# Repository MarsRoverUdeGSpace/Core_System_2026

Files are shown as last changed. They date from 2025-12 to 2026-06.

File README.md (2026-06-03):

# Core System 2026

Core electronics, embedded firmware, and ROS 2 integration workspace for the UdeG Space 2026 rover platform.

Project logo

## Overview

This repository contains the validated `Kukulcan Rev A` controller hardware, the primary rover MCU firmware, and the ROS 2 workspace used to integrate the embedded system with the rest of the stack.

The current main firmware path, `kukulcan/firmware/upio-ros2/`, is a working ESP32-S3 implementation built on Arduino, FreeRTOS, and micro-ROS, with an AUTOSAR-inspired layered architecture deployed on real hardware.

This MCU sits at the intersection of the rover core system and the autonomous navigation stack for the Mars Rover UdeG Space Maya rover in URC 2026. It concentrates the odometry and control interfaces needed for vehicle state estimation and low-level motion integration, including wheel encoders, dual-IMU integration across the wider system, GNSS, altimeter data, communications with RoboClaw motor controllers, and communications with the main processing unit based on the NVIDIA Jetson Orin Nano.

The platform has already been validated on real hardware and is intended to continue system-level validation during field testing, including work planned for the Mars Desert Research Station.

## Current release state

This repository is past initial bring-up and already contains active work in four areas:

- `kukulcan/hardware/`: KiCad MCU design, 3D exports, fabrication outputs, and PCBA files for `MCU RevA`
- `kukulcan/firmware/upy/`: MicroPython-based sensor and UI bring-up
- `kukulcan/firmware/upio-ros2/`: ESP32-S3 PlatformIO firmware using Arduino, FreeRTOS, micro-ROS, and an AUTOSAR-inspired layered architecture
- `src/`: ROS 2 workspace with custom messages, a local `teleop_twistmux_node`, and vendored micro-ROS packages

As of June 2, 2026, this repository is the stable core-system release line for the rover MCU and ROS-facing embedded interface used by AutoNav.

Current status summary:

- hardware: validated RevA integration board with tracked manufacturing outputs
- firmware: stable release on real hardware with successful `pio run`
- localization interface: firmware-owned epoch-stamped `/odom`, direct BNO055 IMU, magnetometer, and GNSS streams validated on the Kukulcan PCB and consumed by the AutoNav stack
- ROS 2 workspace: active and buildable for the currently used packages
- control interface: `cmd_vel` response and motor timeout behavior corrected for the stable AutoNav integration path

Verified in this repository review:

- `colcon build --packages-select teleop_twistmux_node micro_ros_msgs drive_base_msgs`
- maintainer-provided successful `pio run` result for `upio-ros2`

## Stable release notes

This release promotes `feature/imu-mag-calibration` as the stable source line for `develop` and `main`.

Release highlights:

- integrated wheel odometry publication from RoboClaw encoder ticks
- added BNO055 magnetometer publishing for Jetson-side calibration and localization checks
- stabilized GNSS `NavSatFix`, IMU, magnetometer, and `/odom` timestamps in ROS epoch time
- made `/odom` reliable so full `nav_msgs/msg/Odometry` samples survive XRCE transport size limits
- bounded reliable publisher waits and scheduler catch-up behavior so delayed odometry acknowledgements do not starve IMU/GNSS publication
- calibrated odometry geometry and ticks-per-revolution values for the physical rover
- corrected `cmd_vel` response behavior and retained independent motor safety timeout handling

## Highlights

- `Kukulcan Rev A` is a 4-layer protected controller board built around an `ESP32-S3R8` with added `32 MB` flash
- the firmware architecture treats micro-ROS as the effective RTE boundary and FreeRTOS tasks as the application execution model
- the project has a reliable micro-ROS + FreeRTOS + Arduino implementation on the target MCU
- firmware `/odom` and direct IMU/GNSS topics now provide the validated inputs for Jetson-side EKF/global-localization testing
- the Jetson-side integration path is already designed into the hardware through the 40-pin expansion/control header

## Repository layout

| Path | Purpose |
| --- | --- |
| `kukulcan/hardware/` | MCU KiCad project, local libraries, manufacturing outputs |
| `kukulcan/firmware/` | Embedded firmware projects |
| `src/` | ROS 2 workspace packages and vendored dependencies |
| `docs/` | Datasheets, design notes, images, and release support material |
| `CONTRIBUTING.md` | Lightweight workflow and contribution rules |

## Primary subsystems

- Hardware: [kukulcan/hardware/README.md](kukulcan/hardware/README.md)
- Firmware: [kukulcan/firmware/README.md](kukulcan/firmware/README.md)
- Main firmware track: [kukulcan/firmware/upio-ros2/README.md](kukulcan/firmware/upio-ros2/README.md)

## Firmware architecture direction

The main embedded firmware track, `upio-ros2`, is not just an implementation of drivers and ROS transport. It is also the project's embedded software architecture reference:

- application logic is kept separate from hardware-facing details
- the runtime environment layer is effectively realized through the micro-ROS integration boundary
- hardware-dependent behavior is pushed into HAL-style modules and lower layers
- FreeRTOS tasking is used to preserve deterministic behavior across sensing, publishing, and actuation paths, effectively expressing the application layer execution model

That AUTOSAR-inspired separation is already a validated project strength and should be treated as part of the stable release narrative. The same applies to the reliable micro-ROS + FreeRTOS + Arduino implementation on the target MCU, which meaningfully reduces integration friction for the rover stack.

## Quick start

```bash
git clone git@github.com:MarsRoverUdeGSpace/Core_System_2026.git
cd Core_System_2026
git checkout main
```

ROS 2 packages can be listed with:

```bash
colcon list
```

The `upio-ros2` firmware lives in:

```bash
cd kukulcan/firmware/upio-ros2
pio run
```

The hardware project opens from:

```text
kukulcan/hardware/MCU/MCU.kicad_pro
```

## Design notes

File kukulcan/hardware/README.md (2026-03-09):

# Kukulcan Hardware

This directory contains the MCU hardware design and tracked fabrication artifacts for the Kukulcan rover controller board.

Current documented board target: `Kukulcan Rev A`, described as validated RevA integration hardware.

## Contents

- `MCU/`: main KiCad project, board file, schematic, local outputs, and board exports
- `Libraries/`: shared symbols, footprints, and 3D models used by the design
- `mfr/`: tracked manufacturing outputs, Gerbers, drills, fab zip, BOM, and CPL

## Primary design files

- Project: `MCU/MCU.kicad_pro`
- Schematic: `MCU/MCU.kicad_sch`
- PCB: `MCU/MCU.kicad_pcb`
- Board solid: `MCU/MCU.stl`
- Exported board model: `MCU/outputs/MCU_board.step`
- Exported schematic PDF: `MCU/outputs/MCU_schematic.pdf`

## Board overview

Kukulcan Rev A is a 4-layer ESP32-based rover controller board intended to bridge embedded control, onboard sensing, and Jetson-side ROS integration.

Key design points:

- MCU: `ESP32-S3R8` with additional `32 MB` flash
- PCB size: `78 x 53 mm`
- PCB thickness: `1.6 mm`
- Copper weight: `1 oz`
- Surface finish: `HASL with lead`
- Mounting: `M3` mounting holes
- Debug/programming: USB JTAG support for programming and debugging

## Power architecture

The board uses a protected `5 V` input architecture with separate power intent for core electronics and auxiliary lighting.

- Allowed input: `5 V`
- Main power entry: two barrel-jack inputs
- Main regulated logic rail: `3.3 V` generated from `5 V` through a `TLV1117-33` LDO
- Auxiliary power rail: separate `5 V` rail for the LED strip
- Power implementation emphasis: three power planes across the 4-layer board

Documented protection features:

- fuse protection
- reverse-polarity protection
- ESD protection
- TVS protection

## Integrated and exposed interfaces

Integrated devices:

- GNSS: `u-blox NEO-M8N`, mounted directly on the PCB
- Barometer/environmental sensor: `BME280`
- IMU: `BNO055`

External connectivity:

- Jetson interface: `40-pin` header intended for ribbon-cable connection to the Jetson Orin Nano as a broader expansion/control interface
- Jetson link currently includes UART plus two GPIO lines connected to the ESP32
- Jetson-side dedicated I2C is reserved for the `BMI088` IMU
- RoboClaw communications: exposed UART
- Expansion bus: exposed I2C header for additional peripherals
- GNSS antenna: coaxial connector for an active GNSS antenna

Planned but not yet implemented:

- external `2.4"` diagnostics display on the exposed I2C bus

## Validation status

Kukulcan Rev A is validated RevA integration hardware.

Maintainer-reported validation status:

- stable embedded firmware can run on the board
- most hardware functions have been validated on real hardware
- GNSS validation is still pending
- diagnostics display support is still pending

## Manufacturing status

Tracked fabrication data already exists for `MCU RevA`:

- Gerbers and drills in `mfr/`
- Fabrication archive in `mfr/MCU_revA_fab.zip`
- Assembly files in `mfr/pcba/`

If the PCB changes, regenerate these outputs in the same commit or a clearly paired follow-up commit.

## Validation evidence

### PCB render

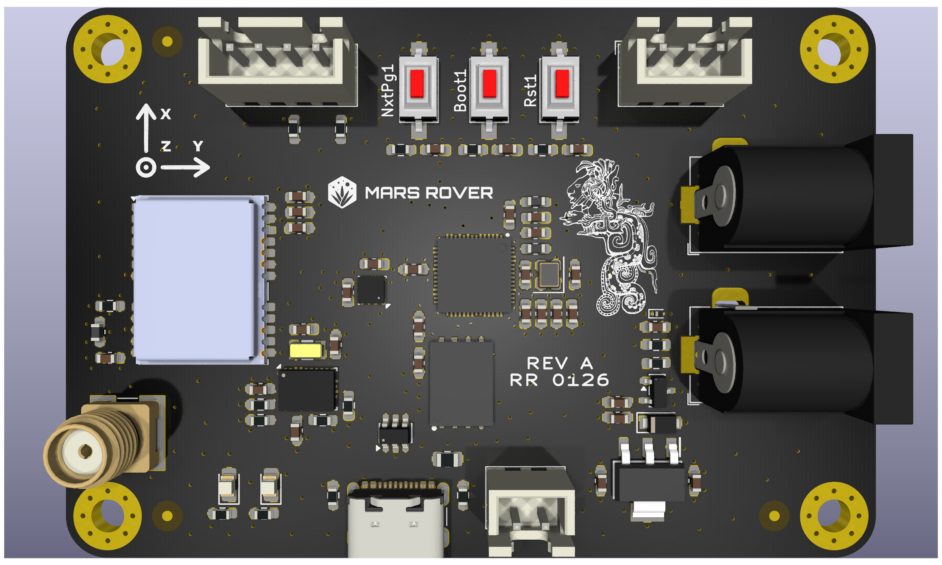
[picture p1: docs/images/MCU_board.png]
Kukulcan Rev A PCB render


Current board render for Kukulcan Rev A.

### Real hardware

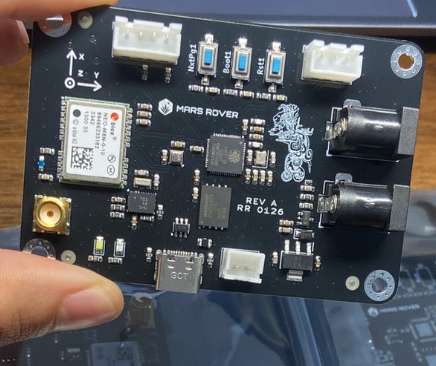
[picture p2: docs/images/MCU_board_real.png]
Kukulcan Rev A assembled board


Assembled Kukulcan Rev A board photographed on real hardware.

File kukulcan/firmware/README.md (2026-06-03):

# Kukulcan Firmware

This directory groups the embedded firmware projects for the Kukulcan controller stack.

The controller firmware in this repository is part of the rover core system and the autonomous navigation stack for the Mars Rover UdeG Space Maya rover in URC 2026. It is responsible for the MCU-side integration of sensing, low-level actuation interfaces, and communication with the Jetson Orin Nano main processing unit.

## Status

The firmware work in this repository is split into two tracks with different roles:

- `upy/`: used for rapid prototyping, sensor bring-up, and integration testing validation
- `upio-ros2/`: current real implementation on ESP32-S3 using PlatformIO, Arduino, FreeRTOS, and micro-ROS

## Projects

- `upy/`: MicroPython-based rapid prototyping and validation path
- `upio-ros2/`: stable firmware implementation and primary release-facing embedded stack

## Current validation

Physical Kukulcan validation confirmed the `upio-ros2/` ROS-facing localization contract: firmware publishes epoch-stamped `/odom`, `/sensors/bno055/imu/data`, `/sensors/bno055/mag`, and `/sensors/gnss/fix` without the prior multi-second publish stalls. The AutoNav Jetson integration path consumes this odometry, IMU, magnetometer, and GNSS contract directly; detailed rates, transport constraints, scheduling behavior, and smoke-test commands are documented in [`upio-ros2/README.md`](upio-ros2/README.md).

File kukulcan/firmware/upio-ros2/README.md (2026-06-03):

# upio-ros2

ESP32-S3 firmware for the Kukulcan MCU using PlatformIO, Arduino, FreeRTOS, and micro-ROS.

## Scope

This firmware is the current embedded integration path between the MCU hardware and the ROS 2 stack. It already includes:

- micro-ROS transport setup
- `cmd_vel` consumption
- motor control tasking
- encoder publishing
- IMU publishing
- GNSS publishing
- wheel odometry publishing
- barometer publishing
- status LED handling

The architecture itself is a primary feature of this firmware: a micro-ROS and FreeRTOS compatible AUTOSAR-style separation between application logic, runtime integration, hardware abstraction, and deterministic task scheduling.

## AUTOSAR-style architecture

This project intentionally emphasizes architecture, not only peripheral bring-up. The firmware follows an AUTOSAR-inspired layered model adapted to the ESP32-S3 and rover use case:

- application layer: mission-facing logic and task orchestration
- runtime environment: controlled interface between application behavior and ROS communication paths
- service and abstraction layers: reusable system services and ECU-facing abstractions
- microcontroller and hardware-facing layers: board-specific buses, peripherals, and device drivers

In repository terms, that maps roughly to:

| Layer intent | Current implementation |
| --- | --- |
| Application Layer | `lib/app/` and its FreeRTOS task model |
| AUTOSAR Runtime Environment | `lib/rte/`, implemented around micro-ROS |
| ECU abstraction and complex drivers | `lib/hal_*`, parts of `lib/config/` |
| MCU-specific configuration | `lib/config/`, board definition, Arduino/ESP32 interfaces |

This architectural separation is already part of the validated firmware value and should be described as a deliberate stable-release feature, not just an internal code organization choice.

In practical terms for this project:

- the RTE layer is essentially the micro-ROS integration boundary
- the application layer is effectively expressed through coordinated FreeRTOS tasks
- the lower layers hold the hardware-specific behavior needed to keep the application side portable and organized

## micro-ROS implementation significance

This firmware also demonstrates a reliable implementation of micro-ROS on top of FreeRTOS with the Arduino framework on ESP32-S3 hardware. That matters because current documentation around this combination is still weaker than the more common reference paths.

For this project, that combination is not experimental anymore. It is part of the validated embedded stack and materially lowers the integration barrier for rover development by:

- simplifying embedded ROS 2 adoption on the target MCU
- preserving a practical Arduino-based development flow
- keeping deterministic task partitioning through FreeRTOS
- exposing ROS communication through an architecture-aligned RTE layer

## Architecture diagrams

### AUTOSAR-inspired layering

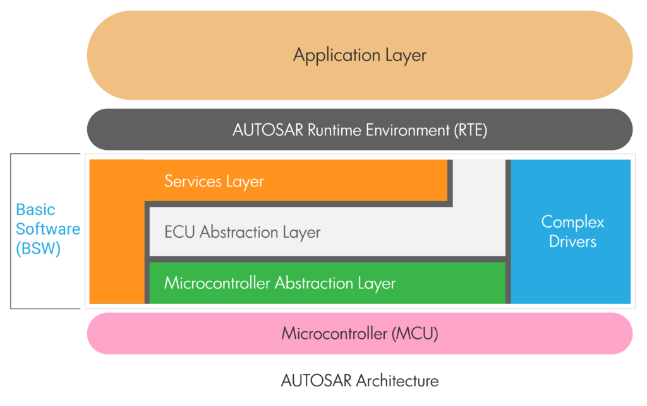
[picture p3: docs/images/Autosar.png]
AUTOSAR-inspired firmware architecture


AUTOSAR-inspired layering used by the firmware. In this project, the runtime environment is effectively realized through micro-ROS and the application layer is expressed through coordinated FreeRTOS tasks.

### micro-ROS stack reference

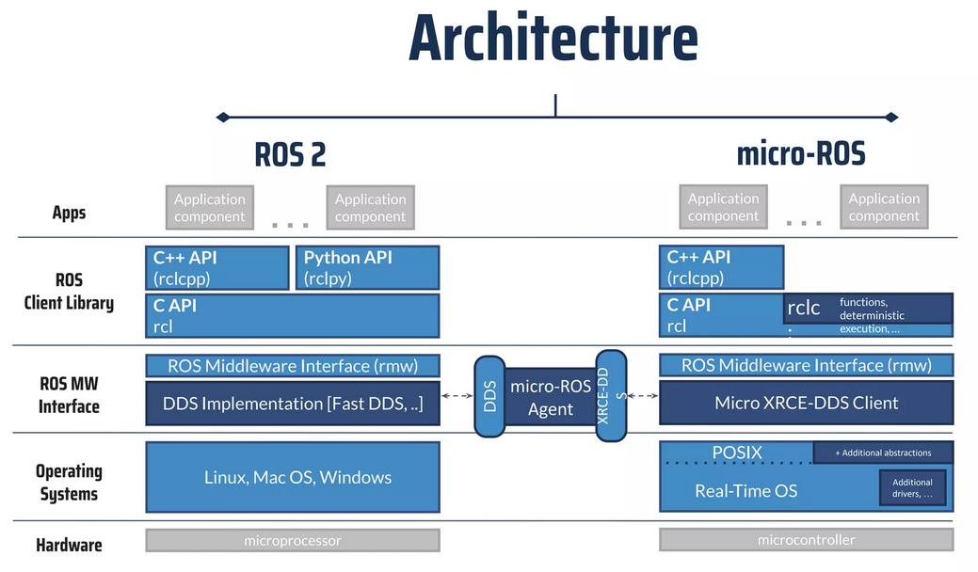
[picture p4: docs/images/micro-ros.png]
micro-ROS architecture reference


micro-ROS architecture reference for the implemented FreeRTOS plus Arduino stack on the ESP32-S3 target.

## Layout

| Path | Purpose |
| --- | --- |
| `src/main.cpp` | Arduino entry point |
| `lib/app/` | task creation and scheduling |
| `lib/rte/` | micro-ROS runtime integration |
| `lib/config/` | hardware pins, buses, queues, and shared objects |
| `lib/hal_*` | hardware abstraction modules for motors, encoders, IMU, altitude, and status LEDs |
| `platformio.ini` | PlatformIO environment and dependencies |

## Runtime model

The current architecture follows the intent described in `AGENTS.md`:

- one task services micro-ROS executor work
- one publisher task emits cached sensor data at fixed periods
- one motor task consumes `cmd_vel` messages and applies a timeout stop
- sensor work lives in dedicated HAL tasks instead of inside the executor

This is the stable release runtime model because it keeps sensor access, motor control, and ROS communication separated while preserving bounded latency for the AutoNav stack.

## Sensor and odometry runtime behavior

The firmware intentionally prioritizes motor control and the micro-ROS runtime loop while keeping sensor traffic at rates appropriate for localization and diagnostics:

| Topic or operation | Configured rate | Notes |
| --- | ---: | --- |
| micro-ROS executor work | 200 Hz | `5 ms` application/RTE period |
| motor control update | 100 Hz | `10 ms` motor task; unchanged commands are not retransmitted to RoboClaw |
| `/sensors/bno055/imu/data` | 25 Hz | Quaternion, angular velocity, and linear acceleration with covariance |
| `/sensors/bno055/mag` | 5 Hz | Magnetic field diagnostic/localization input |
| `/sensors/gnss/fix` | 5 Hz | `NavSatFix`; fix status indicates whether coordinates are valid |
| `/sensors/roboclaw/encoders/*/ticks` | 10 Hz | Primary raw encoder telemetry used to validate wheel acquisition |
| `/sensors/roboclaw/encoders/*/qpps` | Diagnostic only | Sampled periodically; never gates tick validity or odometry |
| `/odom` | 10 Hz | Wheel odometry with `odom` -> `base_footprint` frames |
| `/sensors/bme280/*` | 1 Hz | Environmental telemetry |

Sensor HAL tasks share the I2C bus through a mutex. The BNO055 task retries initialization after boot-time failures rather than requiring a controller reset. RoboClaw wheel tick reads are the validity source for odometry; optional QPPS reads are deliberately excluded from that path so a failed diagnostic query cannot discard usable encoder data.

`/odom` must use reliable micro-ROS QoS. Its serialized `nav_msgs/msg/Odometry` payload includes two covariance matrices and exceeds the `512` byte best-effort XRCE transport MTU configured by the generated micro-ROS client library. Reliable transport provides fragmentation history for the full message; changing `/odom` back to best-effort results in a discovered publisher with no received odometry samples. Reliable publisher session waits are bounded to `5 ms` so an odometry acknowledgement delay cannot stall the shared publisher task and starve IMU or GNSS output.

Timestamped localization topics use synchronized ROS epoch time only. The RTE captures a synchronized epoch/monotonic anchor and derives publish stamps locally without taking the micro-ROS transport mutex on every sensor sample. Before epoch synchronization is available, timestamped localization samples are withheld rather than being emitted in MCU uptime time. This prevents mixed time domains from entering EKF or NavSat processing.

The publisher scheduler skips missed slots after a transport delay rather than replaying a burst of overdue messages. Health pings are serialized with the RCL transport and run at `1 Hz`; the independent motor command timeout remains `250 ms`.

## Stable release integration notes

The June 2026 stable release is the firmware contract used by the AutoNav GNSS waypoint navigation milestone. The important integration guarantees are:

- `/odom` is firmware-owned wheel odometry derived from RoboClaw encoder ticks, calibrated ticks-per-revolution, and calibrated rover geometry.
- `/sensors/bno055/imu/data`, `/sensors/bno055/mag`, `/sensors/gnss/fix`, and `/odom` use ROS epoch timestamps only.
- magnetometer output is available for Jetson-side IMU/magnetic calibration checks.
- reliable `/odom` publication is required because the payload is larger than the best-effort XRCE MTU.
- reliable publisher waits are bounded and missed scheduler periods are skipped, preventing odometry acknowledgement delays from blocking GNSS or IMU output.
- motor command handling responds to `cmd_vel` changes while retaining the independent `250 ms` stop timeout.

## Firmware flow

```mermaid
flowchart LR
  A[FreeRTOS Application Tasks<br/>lib/app] --> B[micro-ROS RTE<br/>lib/rte]
  A --> C[HAL Modules<br/>lib/hal_*]
  B --> D[ROS 2 Agent]
  C --> E[Motors]
  C --> F[IMU]
  C --> G[BME280]
  C --> H[Encoders]
  I[lib/config] --> A
  I --> B
  I --> C
```

This diagram reflects the project's practical layering: FreeRTOS tasks drive application behavior, `lib/rte` exposes the micro-ROS communication boundary, and HAL modules own the hardware-facing work.

## Build

```bash
cd kukulcan/firmware/upio-ros2
pio run
```

Flash:

```bash
pio run -t upload
```

## Current validation status

Maintainer-reported status for the stable release:

- Firmware status: stable release
- Tested hardware: Kukulcan PCB
- Build status: successful `pio run`
- Validation level: thoroughly tested by the maintainer for the current stable AutoNav integration scope

Validated on physical hardware on 2026-05-26:

- BNO055 IMU output observed near the configured `25 Hz` rate.
- BNO055 magnetometer and GNSS output observed at `5 Hz`.
- RoboClaw left and right tick topics observed near the configured `10 Hz` rate after eliminating unnecessary UART traffic and optional-QPPS gating.
- Reliable `/odom` output observed at `10 Hz` while stationary, with `frame_id: odom`, `child_frame_id: base_footprint`, valid timestamp, and zero stationary twist.

Validated again on physical hardware on 2026-05-27 after the ROS epoch and reliable-publisher scheduling fix:

- `/sensors/bno055/imu/data`, `/sensors/gnss/fix`, and `/odom` reported ROS epoch timestamps in the same time domain; the prior IMU uptime stamp failure was removed.
- `/odom` held near `10.2 Hz`, `/sensors/gnss/fix` near `4.8-5.0 Hz`, and `/sensors/bno055/mag` near `5.0 Hz` without the earlier multi-second publication stalls.
- `/sensors/bno055/imu/data` recovered to approximately `22-23.6 Hz` during the captured sample. This is adequate for the current PCB/EKF integration gate, but remains below the configured `25 Hz` target and should be monitored during motion testing.
- Short zero/minimum intervals were still visible in `ros2 topic hz` output. No multi-second starvation remained, but transport jitter should be rechecked if EKF timing warnings reappear.

Latest confirmed build result provided by the maintainer:

```text
==================== [SUCCESS] Took 10.34 seconds ====================
RAM:   16.0% (used 52568 bytes from 327680 bytes)
Flash: 8.9% (used 420573 bytes from 4718592 bytes)
```

## Transport and agent

Current validated serial agent command:

```bash
ros2 run micro_ros_agent micro_ros_agent serial --dev /dev/ttyACM0 -b 921600
```

The same workflow can also be run from Docker, which is the expected Jetson-side deployment path.

## Hardware smoke test

After flashing, verify sensor and wheel odometry health before enabling higher-level localization or navigation:

```bash
pio run -t upload
ros2 topic hz /sensors/bno055/imu/data
ros2 topic hz /sensors/bno055/mag
ros2 topic hz /sensors/gnss/fix
ros2 topic hz /sensors/roboclaw/encoders/left_m1/ticks
ros2 topic hz /sensors/roboclaw/encoders/right_m2/ticks
ros2 topic info -v /odom
ros2 topic echo --once /odom
ros2 topic hz /odom
```

Expected stationary result: the IMU is close to `25 Hz`; magnetometer and GNSS are close to `5 Hz`; encoder tick topics are close to `10 Hz`; `/odom` reports reliable QoS and publishes close to `10 Hz` with zero twist. A GNSS message with `status: -1` and zero coordinates confirms communication but means no usable satellite fix has been acquired yet.

All localization stamps must be in ROS epoch time. Any IMU stamp near controller uptime rather than the current ROS epoch is a firmware fault and blocks EKF/NavSat testing.

## Validated behavior

- micro-ROS transport and executor integration
- FreeRTOS task partitioning aligned with the firmware architecture
- AUTOSAR-inspired layered firmware structure validated in real implementation
- `cmd_vel` handling for motor commands
- sensor publishing pipeline
- recoverable BNO055 initialization and serialized shared-I2C access
- RoboClaw encoder acquisition sufficient for wheel odometry
- reliable wheel odometry publication sized for XRCE transport constraints
- epoch-only localization stamping with bounded reliable publication latency

## Operational notes

- Motor control still uses the current low-level command path with safety timeout handling.
- GNSS output requires an outdoor/adequate-signal fix before coordinates are usable for waypoint navigation.
- If EKF timing warnings reappear, first recheck ROS epoch stamping, reliable `/odom` QoS, and publisher scheduler latency before retuning localization.

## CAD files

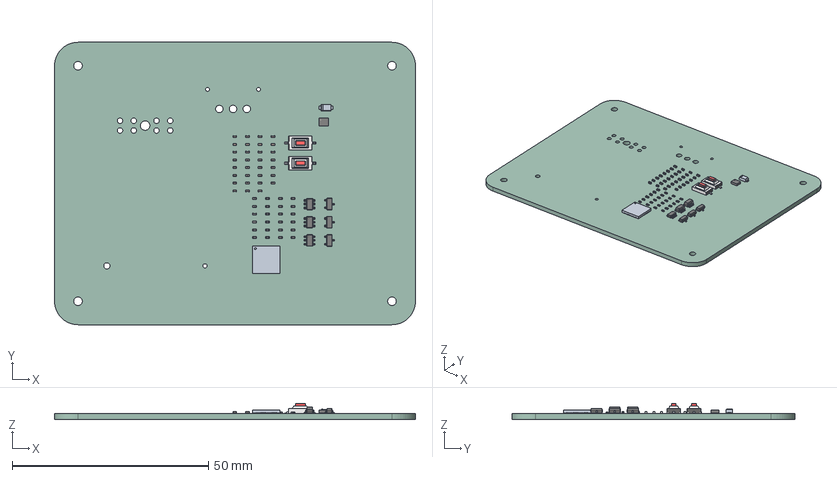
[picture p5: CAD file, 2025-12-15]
kukulcan/hardware/MCU/outputs/MCU_board.step
92.0 x 72.0 x 4.09 mm
L_0402_1005Metric x 4
C_0402_1005Metric x 31
R_0402_1005Metric x 20
SOT-23-6 x 2
MCU_board 1.26.1
SOT-23 x 3
Bosch_LGA-8_2x2.5mm_P0.65mm_ClockwisePinNumbering
TSOT-23-6
SW_SPST_CK_RS282G05A3 x 2
MCU_board 1.35.1
MCU_PCB

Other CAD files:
kukulcan/hardware/MCU/MCU.stl

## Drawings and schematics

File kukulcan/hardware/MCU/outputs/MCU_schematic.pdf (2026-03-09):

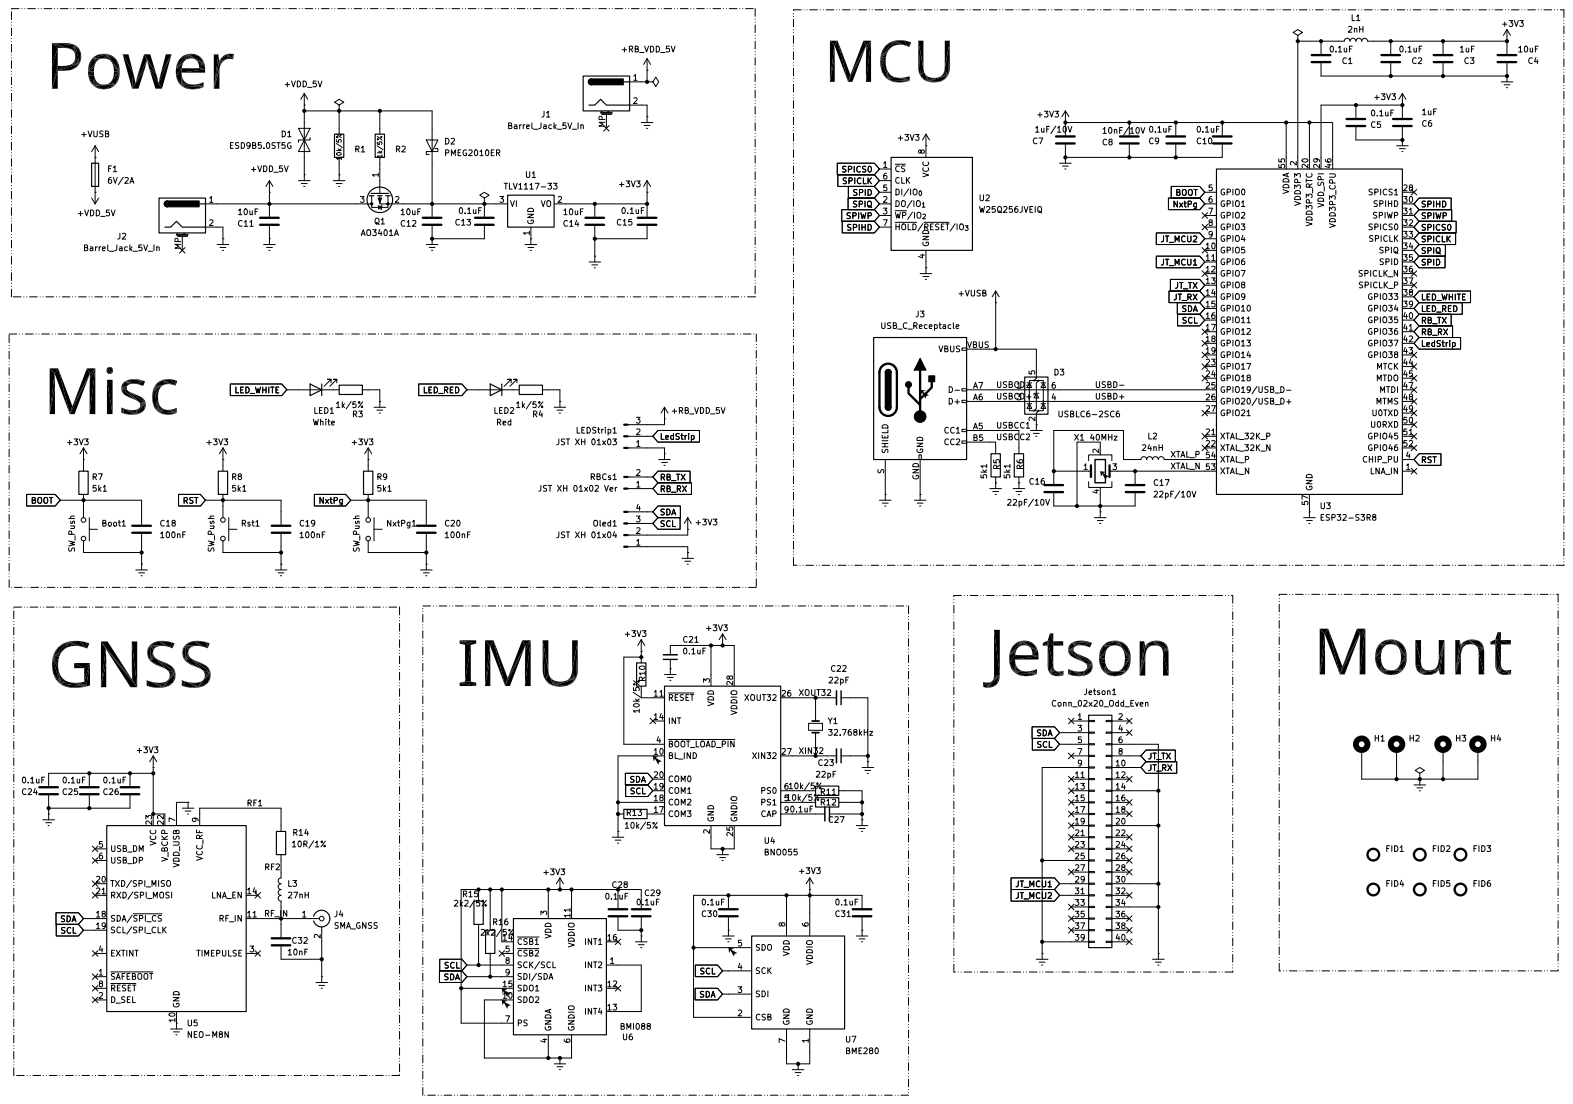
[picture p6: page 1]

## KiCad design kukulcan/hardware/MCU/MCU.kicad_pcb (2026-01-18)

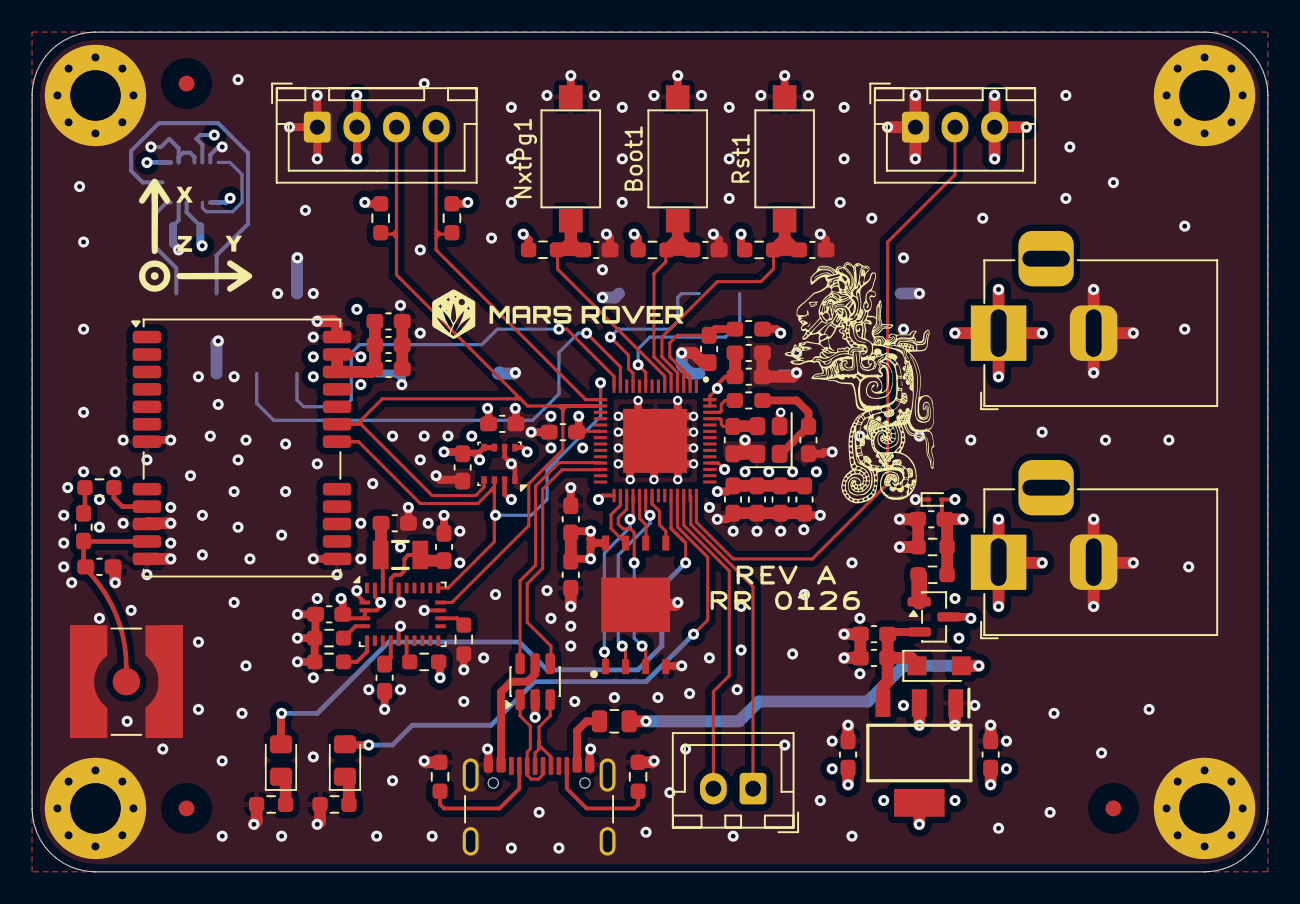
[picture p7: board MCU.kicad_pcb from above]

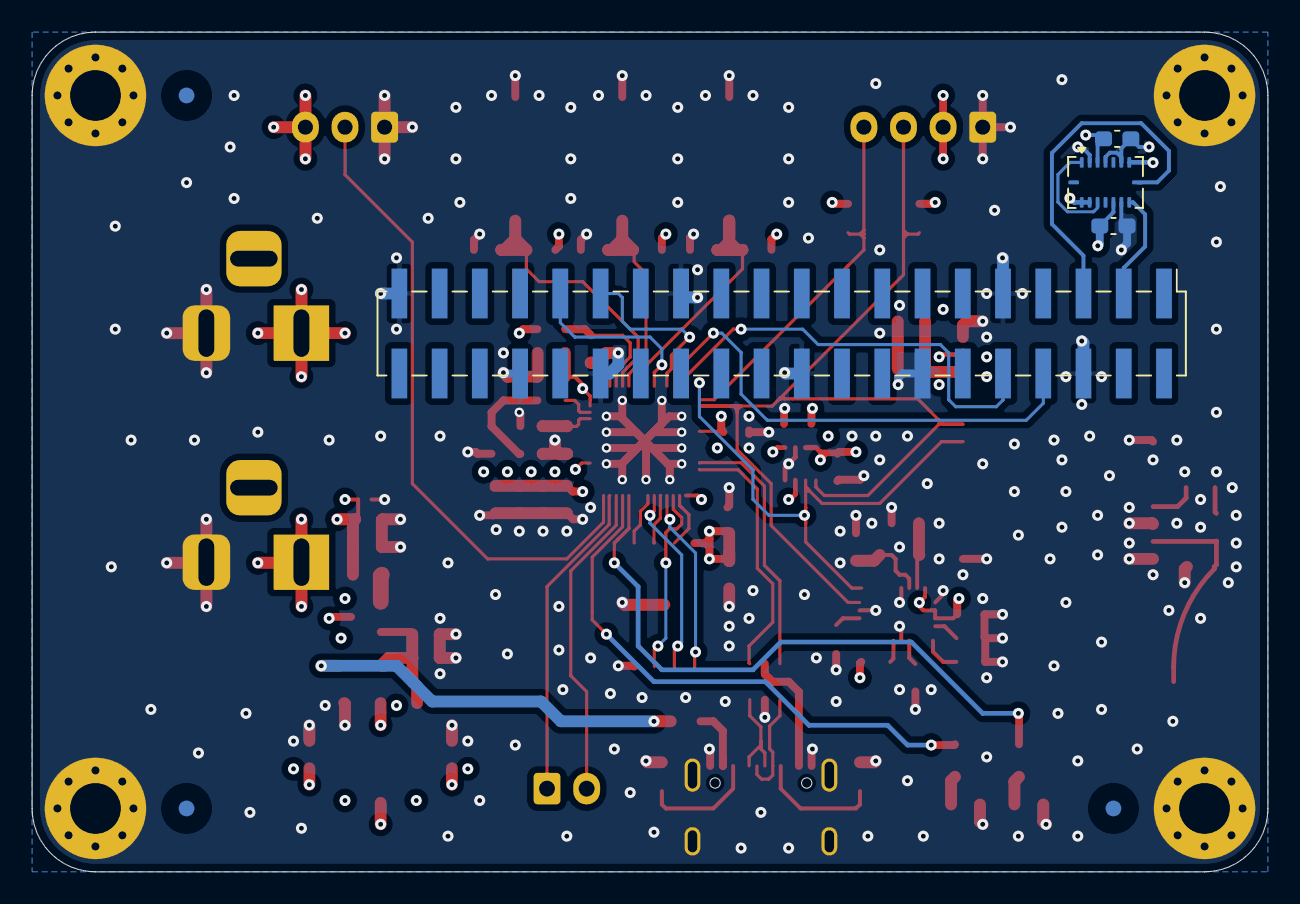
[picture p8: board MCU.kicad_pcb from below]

Board: 4 copper layers, 78.0 x 53.0 mm, 91 parts (7 on the bottom side), 50 nets.

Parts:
Boot1: SW_Push; SW_SPST_CK_RS282G05A3
C1, C2, C5, C9, C10, C13, C15, C21, C24, C25, C26, C27, C28, C29, C30, C31: 0.1uF; C_0603_1608Metric_Pad1.08x0.95mm_HandSolder
C3, C6: 1uF; C_0603_1608Metric_Pad1.08x0.95mm_HandSolder
C4, C11, C12, C14: 10uF; C_0603_1608Metric_Pad1.08x0.95mm_HandSolder
C7: 1uF/10V; C_0603_1608Metric_Pad1.08x0.95mm_HandSolder
C8: 10nF/10V; C_0603_1608Metric_Pad1.08x0.95mm_HandSolder
C16, C17: 22pF/10V; C_0603_1608Metric_Pad1.08x0.95mm_HandSolder
C18, C19, C20: 100nF; C_0603_1608Metric_Pad1.08x0.95mm_HandSolder
C22, C23: 22pF; C_0603_1608Metric_Pad1.08x0.95mm_HandSolder
C32: 10nF; C_0603_1608Metric_Pad1.08x0.95mm_HandSolder
D1: ESD9B5.0ST5G; D_SOD-923
D2: PMEG2010ER; Nexperia_CFP3_SOD-123W
D3: USBLC6-2SC6; SOT-23-6
F1: 6V/2A; Fuse_0805_2012Metric
FID1, FID2, FID3, FID4, FID5, FID6: Fiducial; Fiducial_1mm_Mask3mm
H1, H2, H3, H4: MountingHole_Pad; MountingHole_3.2mm_M3_Pad_Via
J1, J2: Barrel_Jack_5V_In; BarrelJack_Horizontal
J3: USB_C_Receptacle; USB_C_Receptacle_GCT_USB4105-xx-A_16P_TopMnt_Horizontal
J4: SMA_GNSS; SMA_Amphenol_132134-10_Vertical
Jetson1: Conn_02x20_Odd_Even; PinHeader_2x20_P2.54mm_Vertical_SMD
L1: 2nH; L_0603_1608Metric_Pad1.05x0.95mm_HandSolder
L2: 24nH; L_0603_1608Metric_Pad1.05x0.95mm_HandSolder
L3: 27nH; L_0603_1608Metric_Pad1.05x0.95mm_HandSolder
LED1: White; LED_0805_2012Metric_Pad1.15x1.40mm_HandSolder
LED2: Red; LED_0805_2012Metric_Pad1.15x1.40mm_HandSolder
LEDStrip1: JST XH 01x03; JST_XH_B3B-XH-A_1x03_P2.50mm_Vertical
NxtPg1: SW_Push; SW_SPST_CK_RS282G05A3
Oled1: JST XH 01x04; JST_XH_B4B-XH-A_1x04_P2.50mm_Vertical
Q1: AO3401A; SOT-23
R1, R10, R11, R12, R13, R15, R16: 10k/5%; R_0603_1608Metric_Pad0.98x0.95mm_HandSolder
R2, R3, R4: 1k/5%; R_0603_1608Metric_Pad0.98x0.95mm_HandSolder
R5, R6, R7, R8, R9: 5k1; R_0603_1608Metric_Pad0.98x0.95mm_HandSolder
R14: 10R/1%; R_0603_1608Metric_Pad0.98x0.95mm_HandSolder
RBCs1: JST XH 01x02 Ver; JST_XH_B2B-XH-A_1x02_P2.50mm_Vertical
Rst1: SW_Push; SW_SPST_CK_RS282G05A3
U1: TLV1117-33; SOT230P700X180-4N
U2: W25Q256JVEIQ
U3: ESP32-S3R8
U4: BNO055; LGA-28_5.2x3.8mm_P0.5mm
U5: NEO-M8N; ublox_NEO
U6: BMI088; Bosch_LGA-16_4.5x3mm_P0.5mm_LayoutBorder7x1y_ClockwisePinNu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
U7: BME280; Bosch_LGA-8_2.5x2.5mm_P0.65mm_ClockwisePinNumbering
X1: 40MHz; Crystal_SMD_2520-4Pin_2.5x2.0mm
Y1: 32.768kHz; Crystal_SMD_3.2x1.5mm
svg2mod: G***; kukulcan
svg2mod#2: G***; MarsRover
svg2mod#3: G***; IMU_Axes_XYZ

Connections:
+3V3: C2.1, C3.1, C4.1, C5.1, C6.1, C7.1, C8.1, C9.1, C10.1, C14.1, C15.1, C21.2, C24.1, C25.1, C26.1, C28.1, C29.1, C30.1, C31.1, L1.1, Oled1.2, R7.1, R8.1, R9.1, R10.1, R15.2, R16.2, U1.2 (VO), U1.4, U2.8 (VCC), U3.20 (VDD3P3_RTC), U3.29 (VDD_SPI), U3.46 (VDD3P3_CPU), U3.55 (VDDA), U3.56 (VDDA), U4.3 (VDD), U4.4 (~BOOT_LOAD_PIN), U4.28 (VDDIO), U5.22 (V_BCKP), U5.23 (VCC), U6.3 (VDD), U6.7 (PS), U6.11 (VDDIO), U6.14 (~CSB1), U6.15 (SDO1), U7.2 (CSB), U7.5 (SDO), U7.6 (VDDIO), U7.8 (VDD)
+RB_VDD_5V: J1.1, LEDStrip1.3
+VDD_5V: C11.1, D1.2 (A2), D2.2 (A), F1.2, J2.1, Q1.3 (D), R1.1, R2.1
+VUSB: D3.5 (VBUS), F1.1, J3.A4, J3.A9, J3.B4, J3.B9
/RF1: R14.1, U5.9 (VCC_RF)
/RF2: L3.1, R14.2
/RF_IN: C32.2, J4.1 (In), L3.2, U5.11 (RF_IN)
/USBCC1: J3.A5 (CC1), R6.1
/USBCC2: J3.B5 (CC2), R5.1
/USBCD+: D3.3 (I/O2), J3.A6 (D+), J3.B6 (D+)
/USBCD-: D3.1 (I/O1), J3.A7 (D-), J3.B7 (D-)
/USBD+: D3.4 (I/O2), U3.26 (GPIO20/USB_D+)
/USBD-: D3.6 (I/O1), U3.25 (GPIO19/USB_D-)
/XIN32: C23.2, U4.27 (XIN32), Y1.1
/XOUT32: C22.2, U4.26 (XOUT32), Y1.2
/XTAL_N: C17.1, U3.53 (XTAL_N), X1.3
/XTAL_P: L2.2, U3.54 (XTAL_P)
BOOT: Boot1.1, C18.1, R7.2, U3.5 (GPIO0)
GND: Boot1.2, C1.2, C2.2, C3.2, C4.2, C5.2, C6.2, C7.2, C8.2, C9.2, C10.2, C11.2, C12.2, C13.2, C14.2, C15.2, C16.1, C17.2, C18.2, C19.2, C20.2, C21.1, C22.1, C23.1, C24.2, C25.2, C26.2, C27.1, C28.2, C29.2, C30.2, C31.2, C32.1, D1.1 (A1), D3.2 (GND), H1.1, H2.1, H3.1, H4.1, J1.2, J2.2, J3.A1, J3.A12, J3.B1, J3.B12, J3.S1, J4.2 (Ext), Jetson1.6, Jetson1.9, Jetson1.14, Jetson1.20, Jetson1.25, Jetson1.30, Jetson1.34, Jetson1.39, LEDStrip1.1, NxtPg1.2, Oled1.1, R1.2, R3.1, R4.1, R5.2, R6.2, R11.1, R12.1, R13.1, Rst1.2, U1.1 (GND), U2.4 (GND), U2.9, U3.57 (GND), U4.2 (GND), U4.10 (BL_IND), U4.18 (COM2), U4.25 (GNDIO), U5.7 (VDD_USB), U5.10 (GND), U5.12 (GND), U5.13 (GND), U5.24 (GND), U6.2 (GNDA), U6.4 (GNDA), U6.6 (GNDIO), U6.10 (SDO2), U7.1 (GND), U7.7 (GND), X1.2, X1.4
JT_MCU1: Jetson1.29, U3.11 (GPIO6)
JT_MCU2: Jetson1.31, U3.9 (GPIO4)
JT_RX: Jetson1.10, U3.14 (GPIO9)
JT_TX: Jetson1.8, U3.13 (GPIO8)
LED_RED: LED2.2 (A), U3.39 (GPIO34)
LED_WHITE: LED1.2 (A), U3.38 (GPIO33)
LedStrip: LEDStrip1.2, U3.42 (GPIO37)
unnamed: C1.1, L1.2, U3.2 (VDD3P3), U3.3 (VDD3P3)
unnamed: C16.2, L2.1, X1.1
unnamed: C12.1, C13.1, D2.1 (K), Q1.2 (S), U1.3 (VI)
unnamed: LED1.1 (K), R3.2
unnamed: LED2.1 (K), R4.2
unnamed: Q1.1 (G), R2.2
unnamed: C27.2, U4.9 (CAP)
unnamed: R13.2, U4.17 (COM3)
unnamed: R11.2, U4.6 (PS0)
unnamed: R12.2, U4.5 (PS1)
unnamed: R10.2, U4.11 (~RESET)
unnamed: U6.1 (INT2), U6.13 (INT4)
NxtPg: C20.1, NxtPg1.1, R9.2, U3.6 (GPIO1)
RB_RX: RBCs1.1, U3.41 (GPIO36)
RB_TX: RBCs1.2, U3.40 (GPIO35)
RST: C19.1, R8.2, Rst1.1, U3.4 (CHIP_PU)
SCL: Jetson1.5, Oled1.3, R15.1, U3.16 (GPIO11), U4.19 (COM1), U5.19 (SCL/SPI_CLK), U6.8 (SCK/SCL), U7.4 (SCK)
SDA: Jetson1.3, Oled1.4, R16.1, U3.15 (GPIO10), U4.20 (COM0), U5.18 (SDA/~SPI_CS), U6.9 (SDI/SDA), U7.3 (SDI)
SPICLK: U2.6 (CLK), U3.33 (SPICLK)
SPICS0: U2.1 (~CS), U3.32 (SPICS0)
SPID: U2.5 (DI/IO_{0}), U3.35 (SPID)
SPIHD: U2.7 (~HOLD/~RESET/IO_{3}), U3.30 (SPIHD)
SPIQ: U2.2 (DO/IO_{1}), U3.34 (SPIQ)
SPIWP: U2.3 (~WP/IO_{2}), U3.31 (SPIWP)

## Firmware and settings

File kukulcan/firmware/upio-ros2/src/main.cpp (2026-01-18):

/**
 * @file main.cpp
 * @brief Arduino entry point for upio-ros2 firmware.
 */

#include "app.h"

/**
 * @brief Initialize application layer and start tasks.
 */
void setup(void)
{
  app_Init();
  app_StartTasks();
}

/**
 * @brief Idle loop; work is handled by FreeRTOS tasks.
 */
void loop(void){}

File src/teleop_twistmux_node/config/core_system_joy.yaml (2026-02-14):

core_system:
  ros__parameters:
    joy_topic: "/joy"
    cmd_vel_topic: "/cmd_vel"

    publish_rate_hz: 20.0
    joy_timeout_s: 0.25

    # Axes: adjust if your /joy differs
    axis_linear_x: 1
    axis_angular_z: 0

    # Deadman (must be held to move)
    deadman_button: 5   # RB (common)

    # Speed lock buttons (first pressed wins)
    # Example: A,B,X,Y,LB,RB indices 0..5 (common on Xbox layouts)
    speed_buttons: [0, 1, 2, 3, 4, 5]

    # Presets (N entries must match speed_buttons length)
    linear_scales:  [0.10, 0.20, 0.35, 0.50, 0.75, 1.00]
    angular_scales: [0.25, 0.45, 0.65, 0.80, 1.00, 1.00]

    # If no speed button is held, use this preset index
    default_speed_index: 0

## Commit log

2025-08-04 chore: extend .gitignore for PlatformIO/Arduino build output (#2)
2025-12-07 feat(hw-kukulcan): integrate current MCU board version
    [MCU.kicad_pcb, MCU.kicad_sch, MCU_board.step]
2025-12-07 chore(repo): normalize layout to kukulcan/{hardware,firmware} and docs/
    [MCU.kicad_pcb, MCU.kicad_sch, MCU_board.step]
2025-12-07 chore(repo): reset .gitignore for KiCad, firmware, Python, and ROS 2 workspace
2025-12-09 feat(kukulcan-fw): add upio_ros2 firmware config layer, uart pin config, and tested in target Jetsono Orin Nano
2025-12-09 docs(datasheets): esp32-s3 datasheet and user manual
2025-12-15 feat(kukulcan-hw): 3D models lfs pointer fix
    [MCU_board.step]
2025-12-17 feat(kukulcan): several layout and schematic improvements, tasks pending. PCIe connector out.
    [MCU.kicad_pcb, MCU.kicad_sch]
2025-12-21 feat(kukulcan): current beta
    [MCU.kicad_pcb, MCU.kicad_sch]
2025-12-31 feat(kukulcan): final schematic draft
    [MCU.kicad_pcb, MCU.kicad_sch]
2026-01-09 feat(kukulcan): partial final PCB draft, GNSS pending
    [MCU.kicad_pcb, MCU.kicad_sch]
2026-01-16 hw(libs): update footprints and 3d models
2026-01-16 hw(mcu): update schematic and pcb
    [MCU.kicad_pcb, MCU.kicad_sch, MCU.stl]
2026-01-16 hw(mfr): add MCU RevA manufacturing outputs
    [MCU-B_Cu.gbr, MCU-B_Mask.gbr, MCU-B_Paste.gbr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]
2026-01-16 chore(lfs): track stl exports
2026-01-16 chore(lfs): store mcu stl in lfs
2026-01-18 fix(kukulcan): I2C impedance change design error fix
    [MCU-B_Cu.gbr, MCU-B_Mask.gbr, MCU-B_Paste.gbr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]
2026-01-28 fix(kukulcan): led resistors fix
    [MCU.kicad_sch]
2026-02-04 feat(kukulcan-fw): add Kukulcan PCB bringup + open-loop cmd_vel
2026-02-04 fix(kukulcan): led resistors fix2
    [MCU.kicad_sch]
2026-02-04 feat(kukulcan): I2C bus and BME280 bring up
2026-02-04 fix(kukulcan): micro-ros RCSOFTCHECK bringup and leds diagnosis
2026-02-05 feat(kukulcan): IMU bringup, 50Hz rate, micro-ros real-time feat
2026-02-13 fix(kukulcan): i2c pull-up
    [MCU.kicad_sch]
2026-02-18 feat(core) hal led status driver
2026-03-09 feat(kukulcan-fw): add RoboClaw M1 encoder HAL and raw publishers
